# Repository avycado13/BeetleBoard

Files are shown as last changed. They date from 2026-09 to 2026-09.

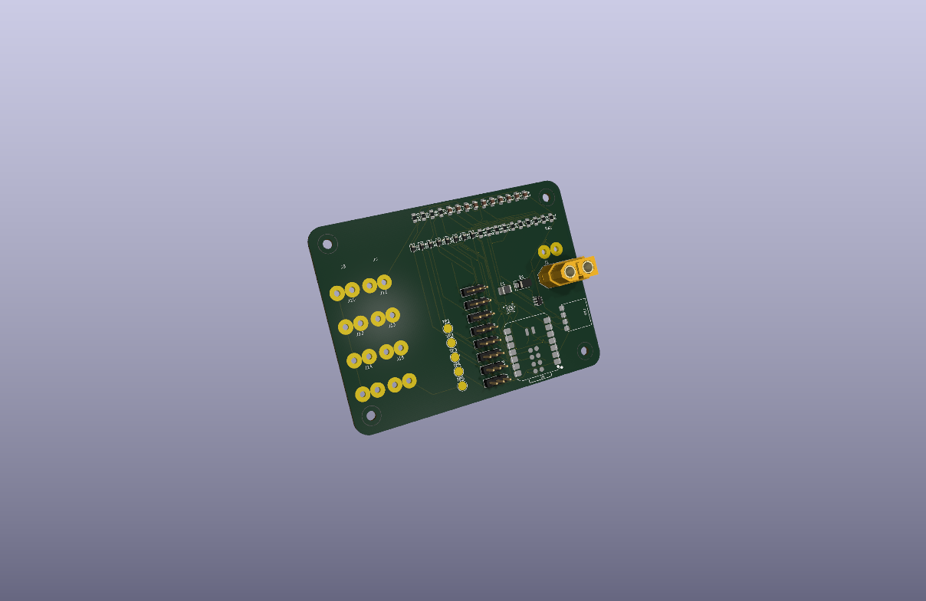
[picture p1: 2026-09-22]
images/BeetleBoard.png

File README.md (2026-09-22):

# BeetleBoard

Ever wanted to build a beetleweight but didn't want the huge mess of wires? No? Too bad. Meet BeetleBoard.
A perfect board for controlling your beetleweight battlebot using an ESP32.

PCB
3D View

## Features:
- 8 ports for ESCs
- 8 motor power ports
- Optional ExpressLRS Receiver
- 6 axis IMU with handling for up to 320Gs
- Software controllable battery undervoltage lockout circuitry
- Battery voltage sensing
- Powered by a XIAO ESP32-C6
- Ability to add a power switch (preferably fingertech)

## Why?
I built this because I saw battlebots at open sauce and thought "I want to make one of those". While looking through things about beetleweights and especially the ones with custom PCBs, I found out that most of the PCBs I found were specifically meant for one design and couldn't really be used for any type of bot. Coincidentally, My friend was trying to run a battlebots elective at our school and would need a control system to test before teaching the students.

## Bill of Materials (BOM)

This is just a rough list compiled from my schematic. The actual one is [here](./BOM.csv)

| Qty | Reference | Value | Package | Description |
|----:|---|---|---|---|
| 1 | U1 | XIAO ESP32-C6 SMD | XIAO | Seeed Studio XIAO ESP32-C6 module (main MCU) |
| 1 | U2 | TPS563200 | SOT-23-6 | 3A synchronous step-down buck converter (5V rail) |
| 1 | U3 | LSM6DSV320XTR | LGA-14 | 6-axis IMU, up to 320G |
| 1 | L1 | 4.7µH | 1210 | Buck converter power inductor |
| 5 | C1, C2, C3, C6, C8 | 22µF | 0805 | Bulk decoupling / output capacitance |
| 5 | C4, C5, C7, C9, C10 | 100nF | 0805 | Decoupling capacitors |
| 9 | R1-R6, R11-R13 | 33kΩ | 0805 | Resistor |
| 1 | R7 | 56kΩ | 0805 | Resistor |
| 1 | R8 | 10kΩ | 0805 | Resistor |
| 1 | R9 | 33.2kΩ | 0805 | Resistor |
| 1 | R10 | 120kΩ | 0805 | Resistor |
| 1 | R14 | 100kΩ | 0805 | Resistor |
| 1 | D1 | SMAJ40CA | SMA | 40V TVS diode (battery reverse/over-voltage protection) |
| 8 | D2-D9 | PESD5V0V1BA | SOD-323 | 5V ESD protection diodes |
| 1 | J1 | AMASS XT60-F | XT60 | Battery connector |
| 8 | J2-J7, J16, J17 | ESC signal port | 1×3 pin header 2.54mm | ESC signal power ports A-H |
| 8 | J8-J15 | VBAT ESC port | Solder wire 2-pin | Motor power ports |
| 1 | J18 | ELRS Receiver | BetaFPV Lite | Optional ExpressLRS receiver socket |
| 1 | SW1 | FingerTech Switch | Solder wire 2-pin | External power switch connection |
| 5 | TP1-TP5 | Test point | 3mm pad | Test/debug points (VBAT, 5V, GND, 3.3V, VBUS) |

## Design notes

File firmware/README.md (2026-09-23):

# BeetleBoard Example Firmware

Comprehensive firmware and modular driver examples for **BeetleBoard**, an ESP32-C6 powered beetleweight battlebot flight & motor control board designed by [avycado13](https://github.com/avycado13).

---

## 📋 Hardware Pinout & Architecture

Based directly on the `BeetleBoard.kicad_sch`, `power.kicad_sch`, and `imu.kicad_sch` schematics:

| Schematic Net | XIAO Pin | ESP32-C6 GPIO | Direction | Function & Hardware Circuitry |
|:---|:---:|:---:|:---:|:---|
| `VBAT_SNS` | **D0** | **GPIO 0** | Input (ADC1_CH0) | Battery voltage sense divider: $R_{10} = 120\text{ k}\Omega$, $R_9 = 33.2\text{ k}\Omega$, $C_7 = 100\text{ nF}$ filter |
| `BUCK_EN` | **D1** | **GPIO 1** | Output | Enable pin (Pin 5) of TPS563200 3A 5V Buck Regulator (active-HIGH) |
| `ESC_A` | **D2** | **GPIO 2** | Output (PWM) | ESC Header **J2** (Pin 1 Signal), 33k pulldown $R_3$, ESD diode $D_2$ |
| `ESC_B` | **D3** | **GPIO 21** | Output (PWM) | ESC Header **J3** (Pin 1 Signal), 33k pulldown $R_2$, ESD diode $D_3$ |
| `ESC_C` | **D4** | **GPIO 22** | Output (PWM) | ESC Header **J4** (Pin 1 Signal), 33k pulldown $R_1$, ESD diode $D_4$ |
| `ESC_D` | **MTDI** | **GPIO 5** | Output (PWM) | ESC Header **J5** (Pin 1 Signal), 33k pulldown $R_4$, ESD diode $D_5$ |
| `ESC_E` | **MTDO** | **GPIO 7** | Output (PWM) | ESC Header **J6** (Pin 1 Signal), 33k pulldown $R_5$, ESD diode $D_7$ |
| `ESC_F` | **MTCK** | **GPIO 6** | Output (PWM) | ESC Header **J7** (Pin 1 Signal), 33k pulldown $R_6$, ESD diode $D_6$ |
| `SPI_CS` | **D5** | **GPIO 23** | Output | Chip Select for LSM6DSV320XTR IMU (Pin 12 CS) |
| `XIAO_TX` | **D6** | **GPIO 16** | Output (UART TX) | J18 ELRS Receiver Header (Pin 1 RX on receiver) |
| `XIAO_RX` | **D7** | **GPIO 17** | Input (UART RX) | J18 ELRS Receiver Header (Pin 2 TX on receiver) |
| `SPI_SCK` | **D8** | **GPIO 19** | Output (SPI CLK) | LSM6DSV320XTR IMU (Pin 13 SCK), 100k pulldown $R_{14}$ |
| `SPI_MISO` | **D9** | **GPIO 20** | Input (SPI MISO) | LSM6DSV320XTR IMU (Pin 1 SDO), 33k pullup $R_{13}$ |
| `SPI_MOSI` | **D10** | **GPIO 18** | Output (SPI MOSI) | LSM6DSV320XTR IMU (Pin 14 SDI) |
| *LED* | Internal | **GPIO 15** | Output | XIAO ESP32-C6 onboard user LED (Active-LOW: LOW=ON, HIGH=OFF) |
| `+5V` | **5V** | VBUS Rail | Power | Generated by TPS563200 buck regulator from battery, powers ESCs & ELRS |
| `+3V3` | **3V3** | 3.3V Rail | Power | Generated by XIAO onboard LDO regulator, powers LSM6DSV320XTR IMU |

> [!NOTE]
> On the PCB, ESC headers **J16** (`ESC_G`) and **J17** (`ESC_H`) include ESD diodes and pulldown resistors for expansion or passthrough, but their signal pins are unrouted to the MCU on this revision.

---

## ⚡ Subsystem Details

### 1. Battery Voltage Sensing & Software UVLO
- **Circuit**: Voltage divider with $R_{10} = 120\text{ k}\Omega$ (top) and $R_9 = 33.2\text{ k}\Omega$ (bottom).
  $$\text{Ratio} = \frac{33.2}{120 + 33.2} = \frac{33.2}{153.2} \approx 0.21671$$
  $$V_{\text{BAT}} = V_{\text{pin}} \times \frac{153.2}{33.2} \approx V_{\text{pin}} \times 4.61446$$
- **Software Undervoltage Lockout (UVLO)**:
  - Automatically identifies battery cell count (2S: ~7.4V, 3S: ~11.1V, 4S: ~14.8V).
  - Continuous exponential moving average filter rejects transient motor punch-out voltage sag.
  - If average cell voltage stays below **3.30V** for $>1.5\text{ s}$, the MCU pulls `BUCK_EN` (GPIO 1) **LOW**, disabling the TPS563200 5V buck regulator to save the LiPo pack from over-discharge damage.

### 2. 6-Channel ESC PWM Generator
- Channels ESC A through F are driven by the ESP32-C6 LEDC hardware PWM generator at **50 Hz** (20 ms period) with **14-bit** resolution.
- Supports both standard unidirectional throttle ($1000\mu\text{s}$ to $2000\mu\text{s}$) and bidirectional drive ($1000\mu\text{s}$ reverse, $1500\mu\text{s}$ neutral, $2000\mu\text{s}$ forward).
- Includes **software arming safety** and **instant emergency stop**.

### 3. LSM6DSV320XTR 6-Axis High-G IMU
- High-g 6-axis IMU rated up to **$\pm 320\text{ g}$** and **$\pm 4000\text{ dps}$**, specifically designed to withstand violent battlebot impacts and meltybrain spin rates.
- Connected via a dedicated 4-wire SPI bus at 4 MHz (Mode 0).
- Verifies identity via `WHO_AM_I` (`0x73`), configures 120 Hz ODR, and streams calibrated acceleration ($g$), angular rates ($\text{dps}$), and rotational spin rate ($\text{RPM}$).

### 4. ExpressLRS (ELRS) / CRSF Receiver
- Standard 4-pin header for BetaFPV Lite, Radiomaster, or Happymodel ELRS receivers.
- Communicates over UART (Serial1) at **420,000 baud** using the standard CRSF protocol.
- Includes full 16-channel 11-bit packet unpacking, Link Quality (LQ), RSSI telemetry, and failsafe detection ($>250\text{ ms}$ packet timeout).

---

## 📂 Project Structure

```
firmware/
├── platformio.ini              # PlatformIO project configuration
├── README.md                   # This documentation
├── include/
│   └── beetleboard_pins.h      # Master pinout & schematic hardware definitions
├── src/
│   ├── main.cpp                # Main production firmware with CLI & control loop
│   ├── power_manager.h/.cpp    # Battery sensing, cell detection & UVLO buck control
│   ├── esc_driver.h/.cpp       # 6-channel LEDC PWM ESC driver
│   ├── imu_lsm6dsv.h/.cpp      # Hardware SPI driver for LSM6DSV320X IMU
│   └── elrs_receiver.h/.cpp    # ExpressLRS CRSF serial protocol decoder
└── examples/
    ├── 01_blink_and_power/     # Standalone: 5V Buck Rail enable & user LED blink
    ├── 02_battery_monitor/     # Standalone: ADC voltage divider & UVLO test
    ├── 03_esc_motor_test/      # Standalone: 6-channel ESC PWM bench sweep
    ├── 04_imu_read_spi/        # Standalone: LSM6DSV320X SPI read & streaming
    └── 05_elrs_telemetry/      # Standalone: ELRS CRSF RC channel decoder
```

---

## 🚀 Building & Flashing

### Option A: Using PlatformIO (Recommended)

1. Open VS Code with the **PlatformIO IDE** extension installed.
2. Open the `firmware/` folder (`File -> Open Folder...`).
3. Connect your BeetleBoard via USB-C.
4. Click **Build** (`✓`) or **Upload** (`→`) on the PlatformIO status bar.
5. Open the Serial Monitor at **115,200 baud**.

Or via CLI:
```bash
cd firmware
pio run --target upload
pio device monitor -b 115200
```

### Option B: Using Arduino IDE

1. Install the **esp32** board package by Espressif (`Tools -> Board -> Boards Manager -> esp32` version 3.0.0 or newer).
2. Select Board: **"Seeed Studio XIAO ESP32C6"** (or **"ESP32C6 Dev Module"**).
3. Set the following under the `Tools` menu:
   - **USB CDC On Boot**: `"Enabled"`
   - **Upload Mode**: `"UART0 / Hardware CDC"`
   - **Flash Size**: `"4MB"`
4. Open `firmware/src/main.cpp` (or any `.ino` sketch under `firmware/examples/`).
5. Click **Upload** and open the Serial Monitor at 115200 baud.

---

## 💻 Interactive Serial Console

The primary firmware (`main.cpp`) includes a built-in USB Serial command interface:

| Key | Action |
|:---:|:---|
| `s` | **Print full system status** (Battery V, LiPo cells, 5V buck state, ESC PWM, IMU, ELRS) |
| `b` | **Toggle 5V Buck Regulator** (Force enable/disable TPS563200 via `BUCK_EN` GPIO 1) |
| `a` | **Toggle Software Arming** (Arm/Disarm motor outputs) |
| `m` | **Motor Bench Sweep Test** (Gentle 3-second throttle ramp on ESC A) |
| `t` | **Stream IMU Telemetry** (Real-time Accel X/Y/Z, Gyro X/Y/Z, and Yaw RPM) |
| `r` | **Stream ELRS RC Channels** (Real-time stick positions, Link Quality, RSSI) |
| `v` | **Stream Battery Voltage** (Continuous voltage & UVLO status) |
| `u` | **Reset UVLO Cutoff** (Clear undervoltage trip and re-enable 5V rail) |
| `h` / `?` | **Show Help Menu** |

---

## 🛡️ Safety Guidelines for Battlebot Testing

> [!CAUTION]
> **ALWAYS REMOVE ALL WEAPONS AND PROPELLERS BEFORE BENCH TESTING.**
> 1. Ensure the board is disarmed before powering on the battery.
> 2. Keep the robot propped up on a stand so drive wheels cannot contact the bench surface.
> 3. Verify failsafe operation by turning off your transmitter while motors are idling; all ESC outputs should immediately revert to $1000\mu\text{s}$ (stopped).

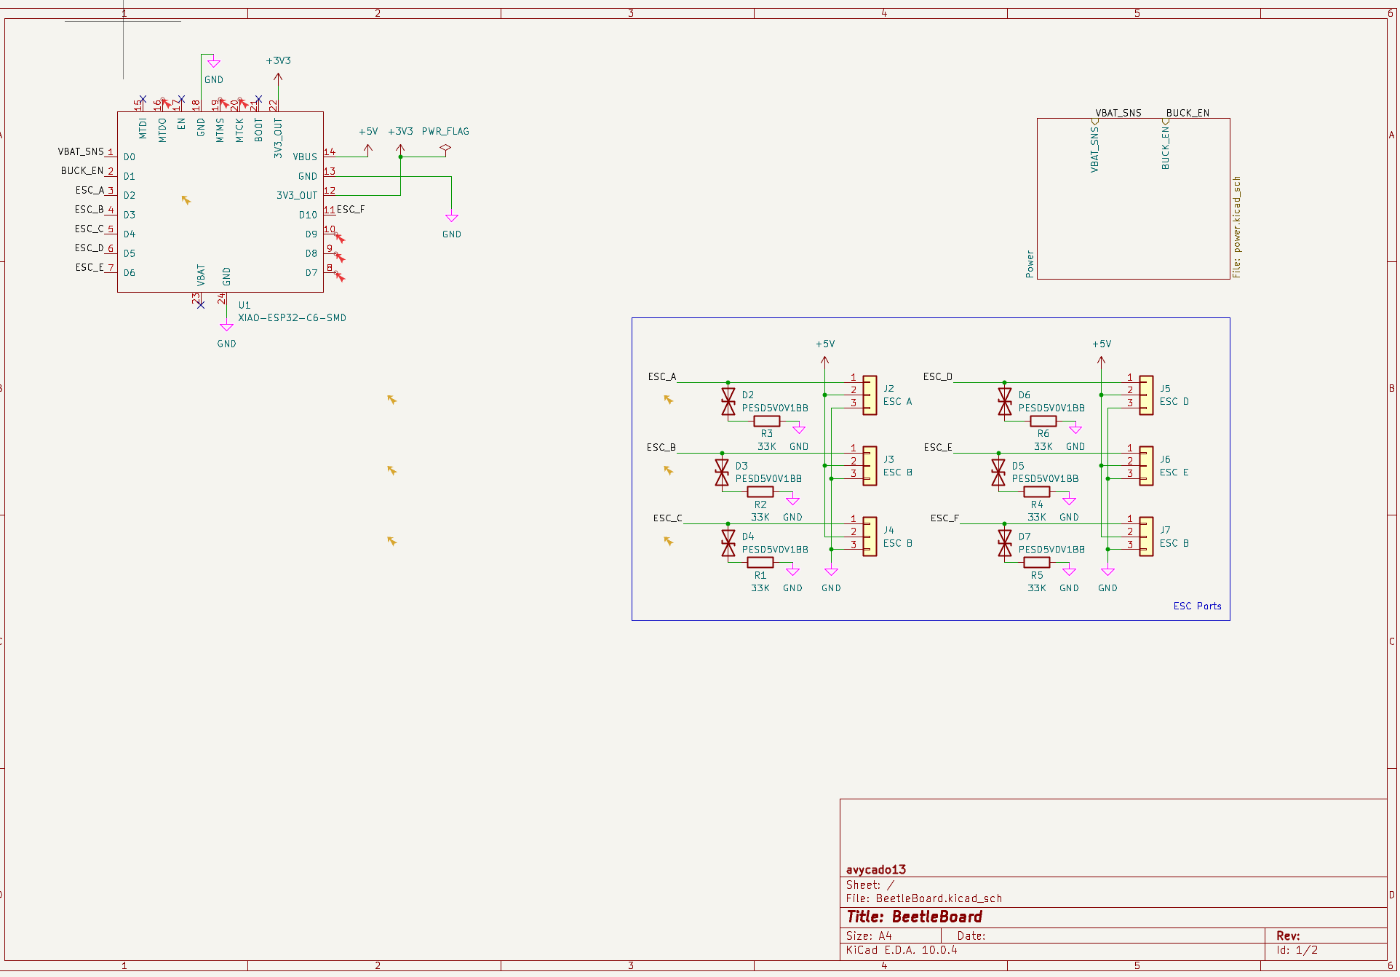
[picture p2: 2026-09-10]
images/beetleboard-3.png

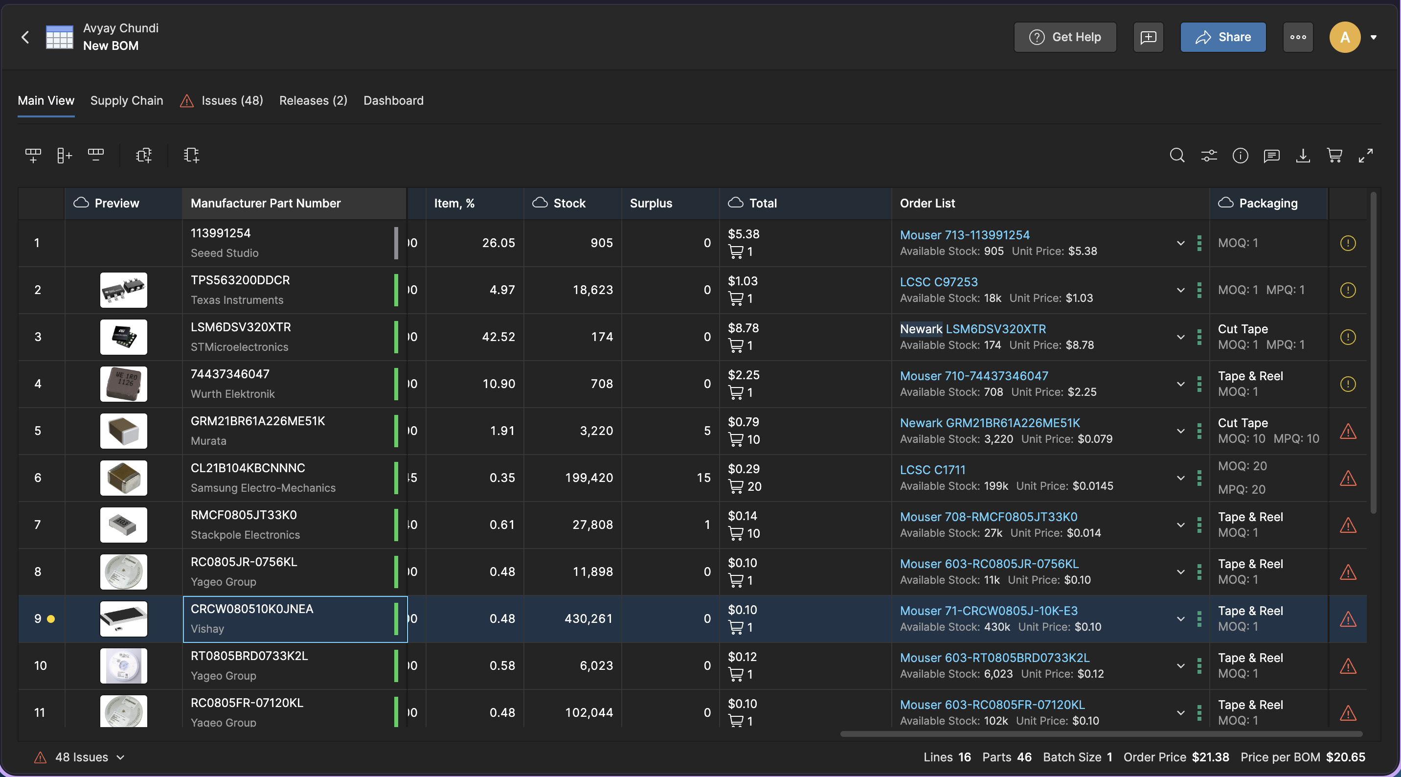
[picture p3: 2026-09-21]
images/beetleboard-13.png

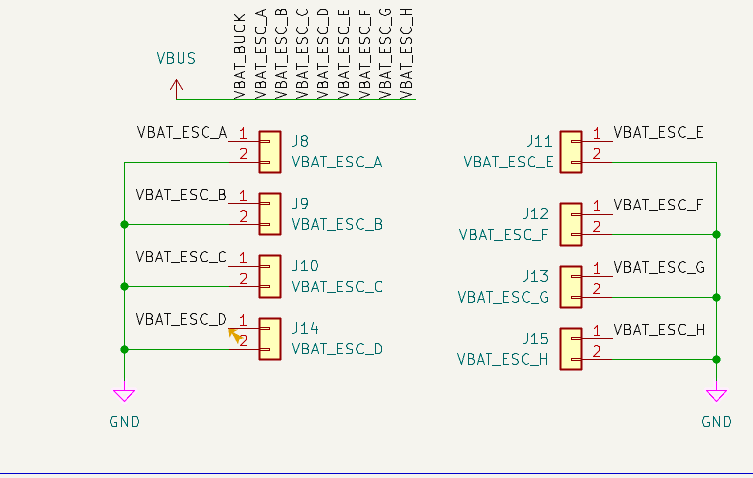
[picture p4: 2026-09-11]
images/beetleboard-5.png

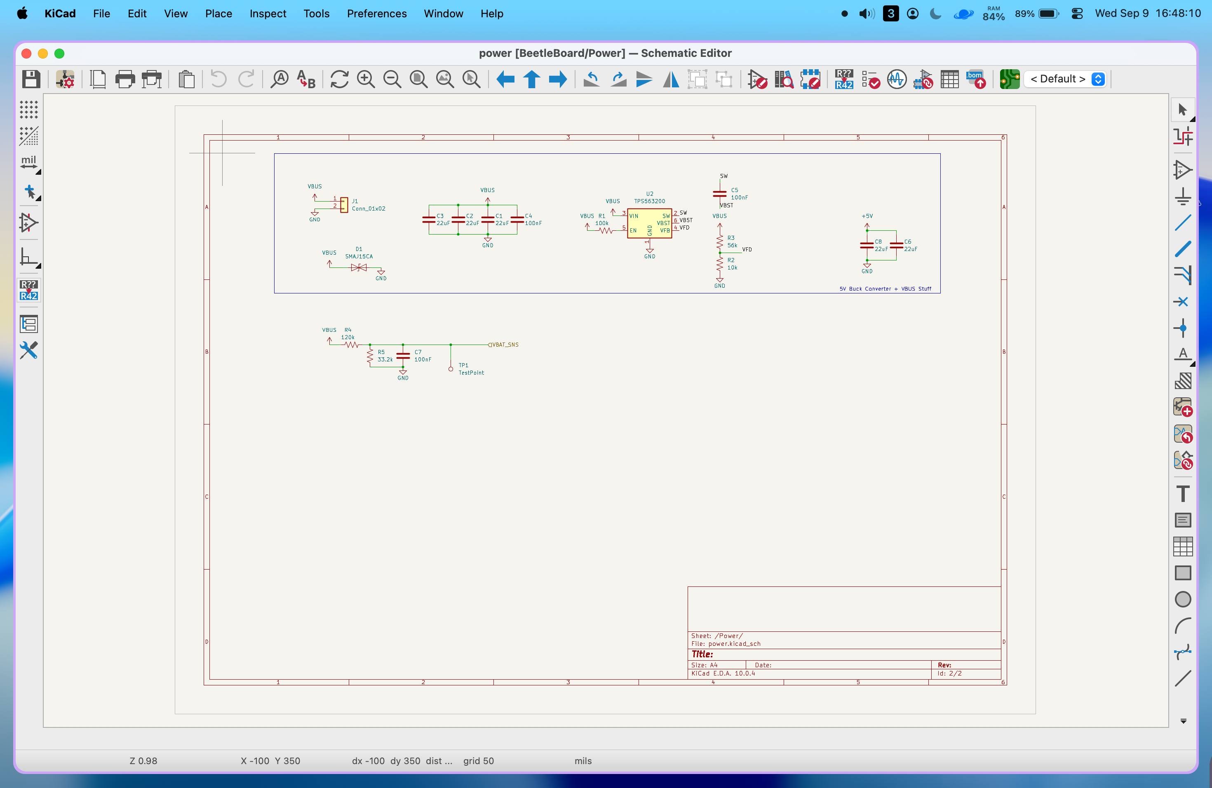
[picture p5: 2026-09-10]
images/beetleboard-1.png

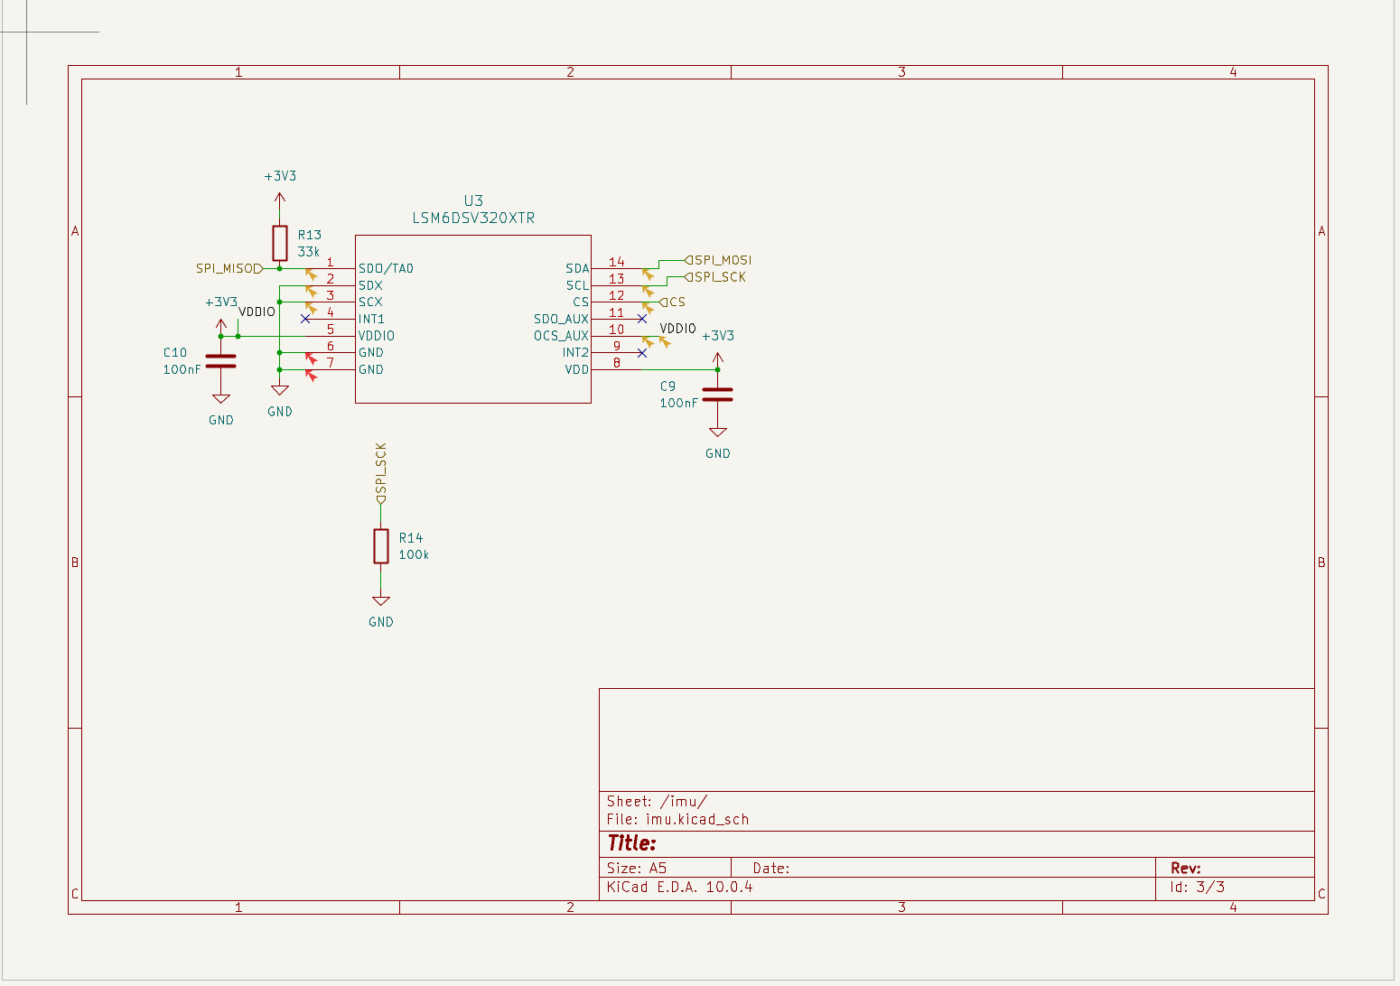
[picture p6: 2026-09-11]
images/beetleboard-6.png

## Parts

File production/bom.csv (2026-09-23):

Designator | Footprint | Quantity | Value | LCSC Part #
C1, C2, C3, C6, C8 | 0805 | 5 | 22uF
C10, C4, C5, C7, C9 | 0805 | 5 | 100nF
D1 | D_SMA | 1 | SMAJ40CA
D2, D3, D4, D5, D6, D7, D8, D9 | D_SOD-323 | 8 | PESD5V0V1BB
J1 | AMASS_XT60-F_1x02_P7.20mm_Vertical | 1 | Battery Connector
J10 | Power_SolderPad_2Pin_P5.08mm_D2.0mm | 1 | VBAT_ESC_C
J11 | Power_SolderPad_2Pin_P5.08mm_D2.0mm | 1 | VBAT_ESC_E
J12 | Power_SolderPad_2Pin_P5.08mm_D2.0mm | 1 | VBAT_ESC_F
J13 | Power_SolderPad_2Pin_P5.08mm_D2.0mm | 1 | VBAT_ESC_G
J14 | Power_SolderPad_2Pin_P5.08mm_D2.0mm | 1 | VBAT_ESC_D
J15 | Power_SolderPad_2Pin_P5.08mm_D2.0mm | 1 | VBAT_ESC_H
J16 | PinHeader_1x03_P2.54mm_Vertical | 1 | ESC G
J17 | PinHeader_1x03_P2.54mm_Vertical | 1 | ESC H
J18 | BetaFPV_ELRS_Lite | 1 | ELRS Reciever
J2 | PinHeader_1x03_P2.54mm_Vertical | 1 | ESC A
J3 | PinHeader_1x03_P2.54mm_Vertical | 1 | ESC B
J4 | PinHeader_1x03_P2.54mm_Vertical | 1 | ESC C
J5 | PinHeader_1x03_P2.54mm_Vertical | 1 | ESC D
J6 | PinHeader_1x03_P2.54mm_Vertical | 1 | ESC E
J7 | PinHeader_1x03_P2.54mm_Vertical | 1 | ESC F
J8 | Power_SolderPad_2Pin_P5.08mm_D2.0mm | 1 | VBAT_ESC_A
J9 | Power_SolderPad_2Pin_P5.08mm_D2.0mm | 1 | VBAT_ESC_B
L1 | 1210 | 1 | 4.7uH
R1, R11, R12, R13, R2, R3, R4, R5, R6 | 0805 | 9 | 33K
R10 | 0805 | 1 | 120k
R14 | 0805 | 1 | 100k
R7 | 0805 | 1 | 56K
R8 | 0805 | 1 | 10K
R9 | 0805 | 1 | 33.2k
SW1 | Power_SolderPad_2Pin_P5.08mm_D2.0mm | 1 | FingerTech Switch
TP1 | TestPoint_Pad_D3.0mm | 1 | TP_VBAT_SNS
TP2 | TestPoint_Pad_D3.0mm | 1 | TP_5V
TP3 | TestPoint_Pad_D3.0mm | 1 | TP_GND
TP4 | TestPoint_Pad_D3.0mm | 1 | TP_3V3
TP5 | TestPoint_Pad_D3.0mm | 1 | TP_VBAT(VBUS)
U1 | XIAO-ESP32-C6-SMD | 1 | XIAO-ESP32-C6-SMD
U2 | SOT-23-6 | 1 | TPS563200
U3 | LGA-14L_2p5X3X0p83_STM | 1 | LSM6DSV320XTR

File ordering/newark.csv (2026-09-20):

Manufacturer Part Number | Manufacturer | Quantity | Order List | Supplier Name | Supplier Part Number | Order List (Supplier Link) | Packaging | MOQ | MPQ | Unit Price, $ | Stock | Supplier Order Quantity | Subtotal, $
LSM6DSV320XTR | STMicroelectronics | 1 | Newark LSM6DSV320XTR | Newark | LSM6DSV320XTR | https://octopart.com/opatz8j6/a1 | Cut Tape | 1 | 1 | 8.78 | 174 | 1 | 8.78
GRM21BR61A226ME51K | Murata | 5 | Newark GRM21BR61A226ME51K | Newark | GRM21BR61A226ME51K | https://octopart.com/opatz8j6/a1 | Cut Tape | 10 | 10 | 0.079 | 3220 | 10 | 0.790
RC0805FR-07100KL | Yageo Group | 1 | Newark RC0805FR-07100KL | Newark | RC0805FR-07100KL | https://octopart.com/opatz8j6/a1 | Cut Tape | 1 | 1 | 0.101 | 113917 | 1 | 0.101

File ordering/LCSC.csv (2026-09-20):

Manufacturer Part Number | Manufacturer | Quantity | Order List | Supplier Name | Supplier Part Number | Order List (Supplier Link) | Packaging | MOQ | MPQ | Unit Price, $ | Stock | Supplier Order Quantity | Subtotal, $
TPS563200DDCR | Texas Instruments | 1 | LCSC C97253 | LCSC | C97253 | https://octopart.com/opatz8j6/a1 |  | 1 | 1 | 1.03 | 18623 | 1 | 1.03
CL21B104KBCNNNC | Samsung Electro-Mechanics | 5 | LCSC C1711 | LCSC | C1711 | https://octopart.com/opatz8j6/a1 |  | 20 | 20 | 0.0145 | 199420 | 20 | 0.2900
PESD5V0V1BA,115 | Nexperia | 8 | LCSC C552583 | LCSC | C552583 | https://octopart.com/opatz8j6/a1 |  | 10 | 10 | 0.0508 | 47280 | 10 | 0.5080
XT60-F | Amass | 1 | LCSC C98734 | LCSC | C98734 | https://octopart.com/opatz8j6/a1 |  | 1 | 1 | 0.4172 | 33851 | 1 | 0.4172

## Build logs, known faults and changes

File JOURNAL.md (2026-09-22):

---
title: "BeetleBoard"
github: "avycado13/beetleboard"
description: "a basic board for making versatile beetleweight battlebots"
created_at: "2026-09-08"
---

My friend wants to do more battlebot type things with 5th and 6th graders so I thought I might make a board that has enough motor and servo ports to be useful for all types of bots and not constrained to one. I guess I am calling it BeetleBoard!
 
# September 8: Added Basic Power Circuitry
I made my circuit to take a LiPo battery and then first it goes through a TVS Diode to protect it from voltage spikes. Then it gets decoupled through 4 Capacitors and toned down to 5v with a buck converter. I also added some battery charge sensing. (I took heavy inspiration from Kieran's [Holy Guacamole](https://github.com/taciturnaxolotl/holy-guacamole/))

Power subsheet
**Total time spent: 2h**

# September 9: Fixed Power Circuitry

So I might be a bit dumb and have for gotten some stuff, so I fixed that up and needed to fiddle with KiCad libraries.
Also, I kinda gave up on implementing a proper undervolting lock out circuit in hardware, so I will just use my voltage sensing to control the enable pin in software. (I forgot to commit this 4 hours ago)

Power Subsheet Rev. 2
**Total time spent: 1h**

# September 9: ESC Ports
After taking way too long to understand the difference between PWM and DShot, I understand it now. Interestingly you can use the same connector layout for both (I think). I added 6 ports for ESCs, they all look like servo ports and can function as such because they can do both DShot and PWM. It might seem a bit excessive to have 6 Servo ports, but because this is for experimentation it should turn out fine. Also did I tell you I decided on a XIAO ESP32-C6 for it?

Main Sheet
**Total time spent: 2h**

# September 10: Added 6 Axis IMU
I was on a huddle with Kian and he told me about the MPU-6050 which is a 6 axis imu. I was debating whether to put an imu on this as it would have been a lot of work to wire up multiple so this board simplifies it a lot. it was actually really simple to wire up as it just used i2c (TIL that its pronounced I squared c) I also added a test point on the 5V Rail and GND.
I might add a header on the board to connect to a radio receiver as apparently ESP32 WiFi signals don't work that great.

New schematic with IMU
**Total time spent: 1h**

# September 10: Added Power distrubution
I kinda forgot that the ESCs require a seperate source of power with a higher voltage to actually power the motors, so i added some power distrubution to the board. It goes directly from the battery through a TVS Diode and some capactors to clean up voltage spikes and decouple it then gets split into 8 connectors for the ESCs and one for the buck converter. I also added an SPST switch on the power connector where i can eventually put a FingerTech Switch or just solder them together.

New power subsheet with distrubution
**Total time spent: 1h**

# September 11: Fixed IMU
I realized that my original IMU wouldn't be able to handle more than 16G, which is really low because on impact it could hit 200G and for meltybrains it would overload because of spinny. Instead, I replaced it with an LSM6DSV320XTR 6 axis IMU that could handle up to 300Gs. I wired it over SPI to connect everything and I put it in its own sheet.

New IMU over SPI
**Total time spent: 1.5h**

# September 11: Added Port for ExpressLRS Receiver
I added a connector for an ExpressLRS receiver because ESP32 bluetooth/WiFi is supposedly really unreliable. It should communicate over UART.

New ELRS Reciever
**Total time spent: 0.5h**

# September 13: Started PCB Layout
I assigned the footprints for components and made a really crappy layout for the PCB that kinda looks like a guitar.

PCB
**Total time spent: 0.5h**

# September 14: Redid PCB Layout and Routed
I redid the layout to be less weird shaped and cheaper to fab. I also routed it in just 2 layers!
Because its about 100mm by 70mm it should only cost 5 bucks to fab.

New PCB Layout
**Total time spent: 1.5h**

# September 17: Wrote README
Today, I prepped it for shipping and mainly wrote the readme. I don't think I need a photo of the README because you can read that. I added a comprehensive list of features!

edit: turns out i do :(

README
**Total time spent: 1h**

# September 20: Made better BOM

I already have a BOM in my README, but I went to Octopart and made a better BOM and consolidated my parts so i will only have to order from three suppliers: LCSC, Mouser, and Newark.

Altium BOM Portal

**Total time spent: 1h**

# September 21: Redid Layout
I redid the layout of the PCB to be neater and changed the solder wire things to be a new custom footprint of 2 5mm circle pads spaced about 5mm apart. I also added M3 Mounting holes offset 6mm x 6mm from each edge. In addition, I also filleted the corners for looks. I forgot to put it when I took the picture but I also added some basic silkscreen.
PCB with new layout
**Total time spent: 2h**

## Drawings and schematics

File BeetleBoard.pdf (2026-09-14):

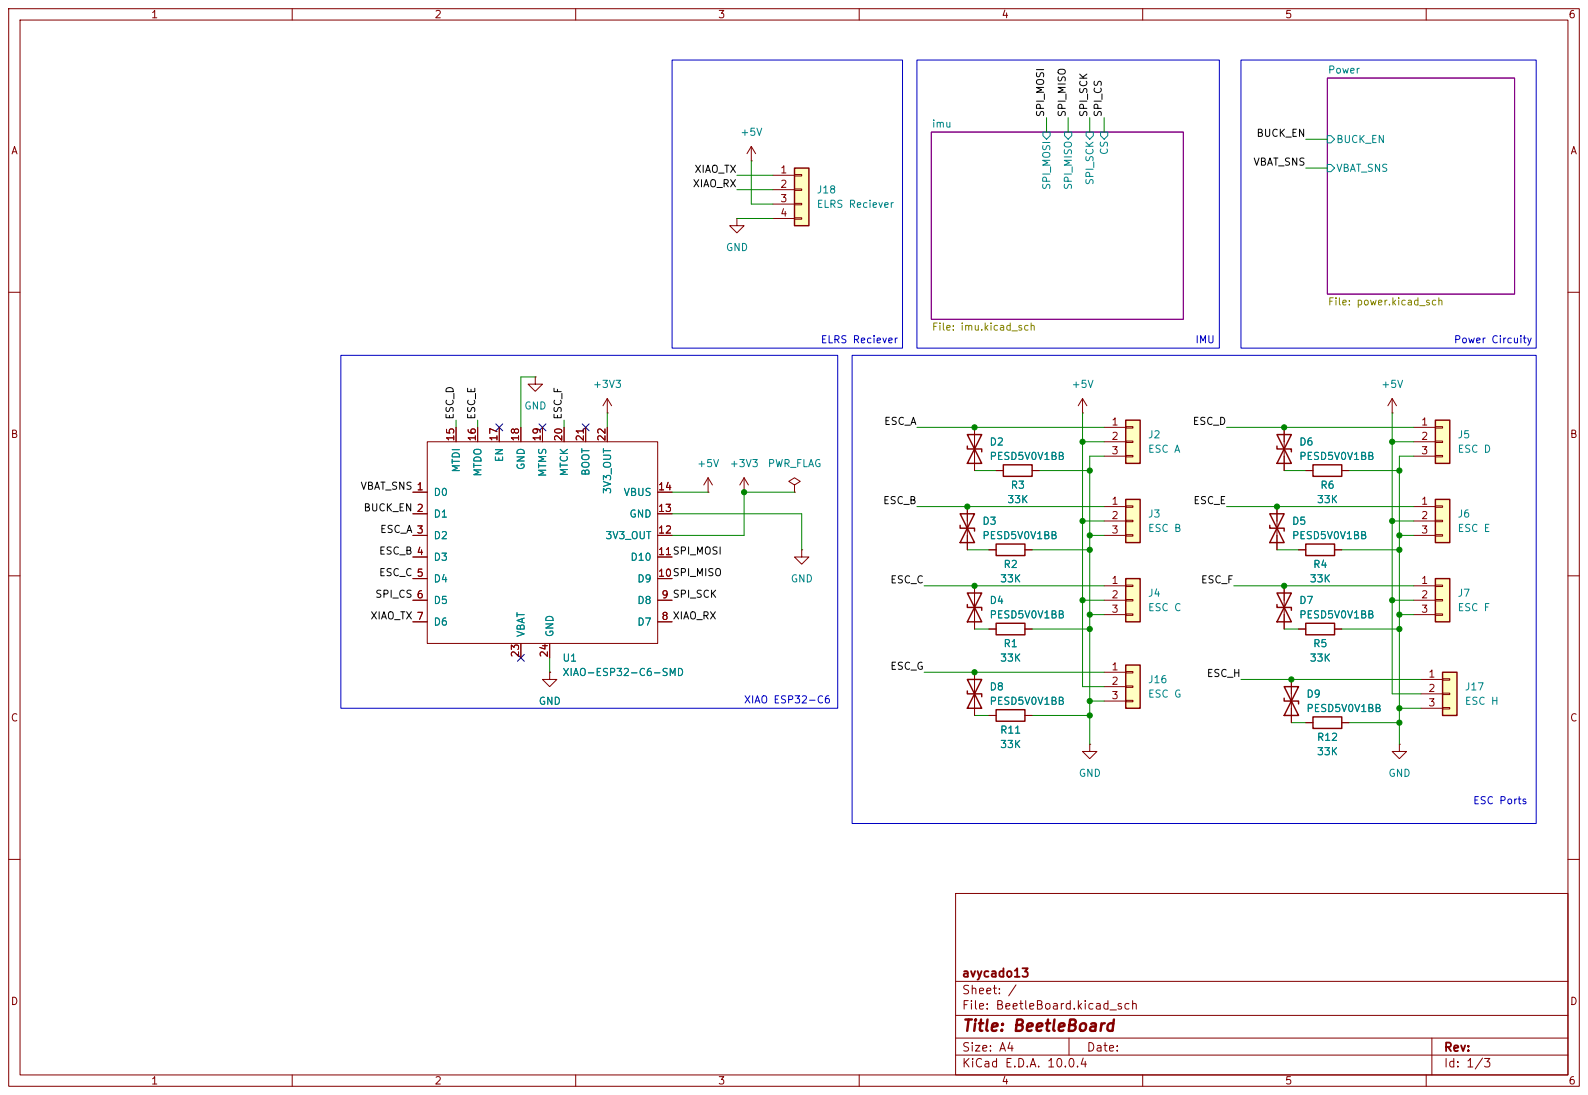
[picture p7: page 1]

Size: A4 | Rev:
KiCad E.D.A. 10.0.4 | Id: 1/3

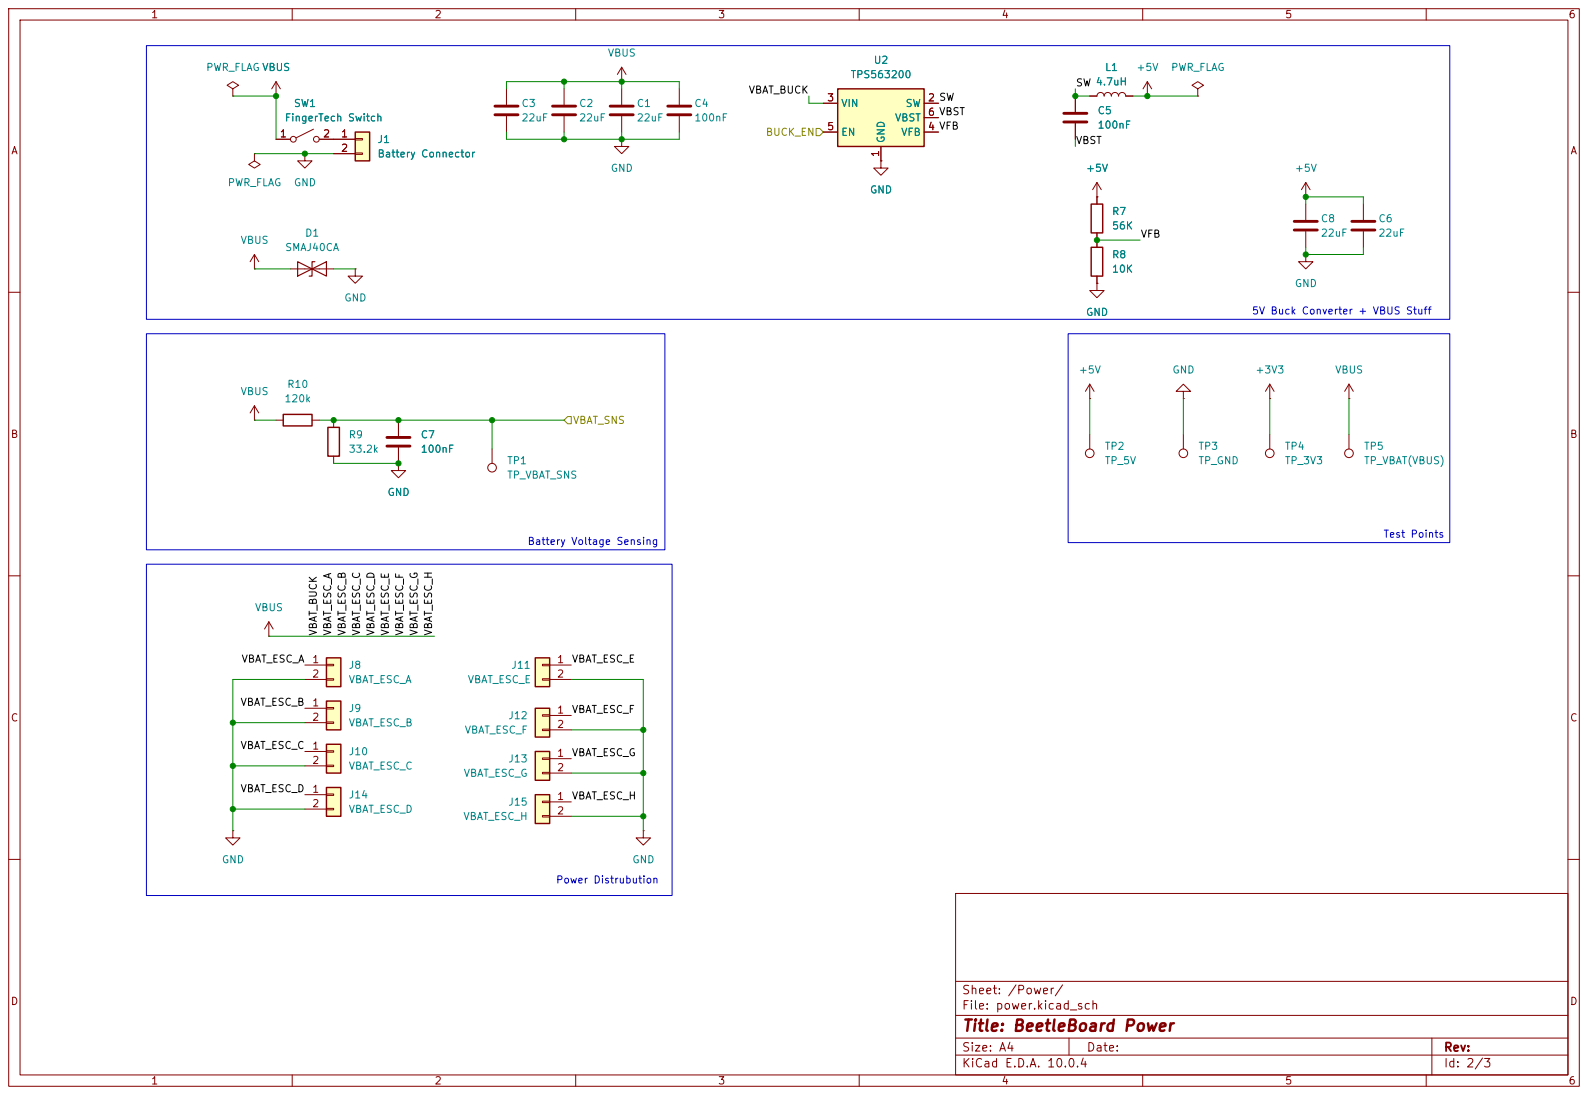
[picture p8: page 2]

Size: A4 | Rev:
KiCad E.D.A. 10.0.4 | Id: 2/3

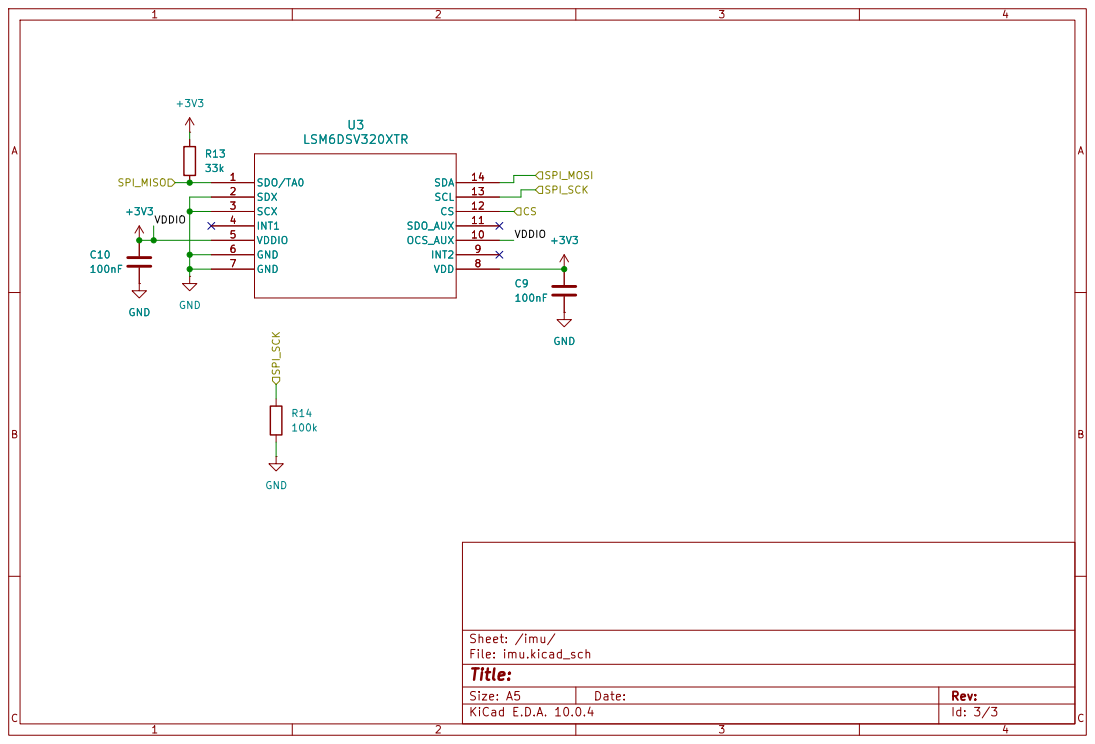
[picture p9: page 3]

Size: A5 | Rev: | C Date:
KiCad E.D.A. 10.0.4 | Id: 3/3

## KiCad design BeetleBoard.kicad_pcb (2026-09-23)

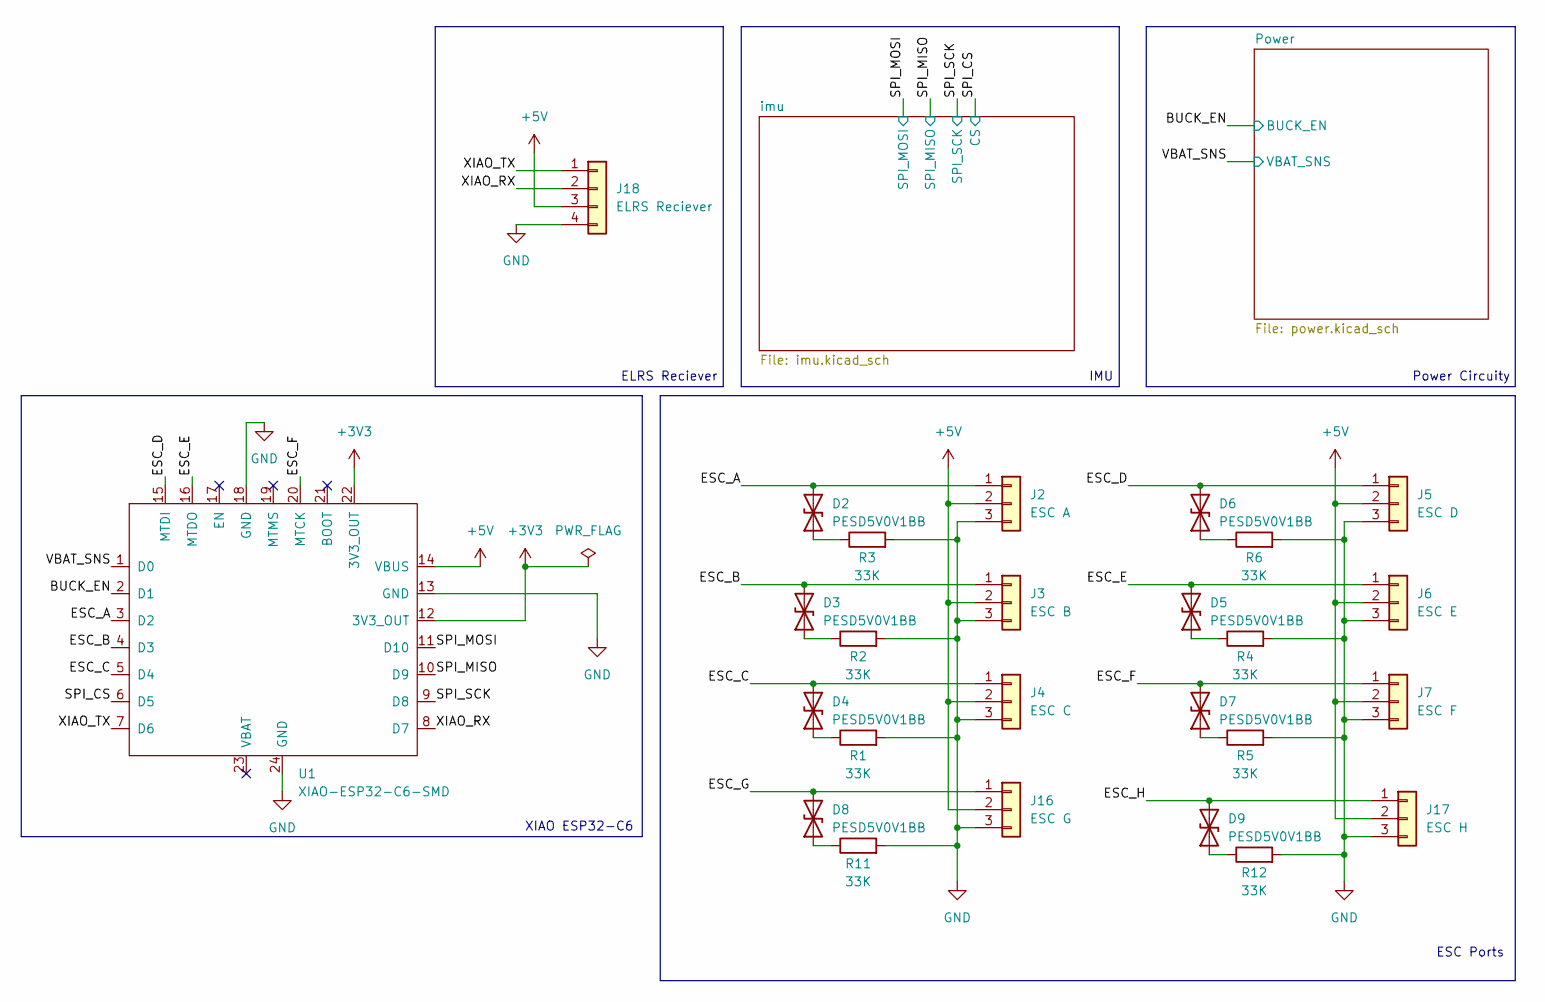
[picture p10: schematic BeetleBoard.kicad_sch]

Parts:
D2, D3, D4, D5, D6, D7, D8, D9: PESD5V0V1BB; D_SOD-323
J2: ESC A; PinHeader_1x03_P2.54mm_Vertical
J3: ESC B; PinHeader_1x03_P2.54mm_Vertical
J4: ESC C; PinHeader_1x03_P2.54mm_Vertical
J5: ESC D; PinHeader_1x03_P2.54mm_Vertical
J6: ESC E; PinHeader_1x03_P2.54mm_Vertical
J7: ESC F; PinHeader_1x03_P2.54mm_Vertical
J16: ESC G; PinHeader_1x03_P2.54mm_Vertical
J17: ESC H; PinHeader_1x03_P2.54mm_Vertical
J18: ELRS Reciever; BetaFPV_ELRS_Lite
R1, R2, R3, R4, R5, R6, R11, R12: 33K; R_0805_2012Metric_Pad1.20x1.40mm_HandSolder
U1: XIAO-ESP32-C6-SMD

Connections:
+3V3: U1.12 (3V3_OUT), U1.22 (3V3_OUT); also elsewhere on the board
+5V: J2.2 (+5V), J3.2 (+5V), J4.2 (+5V), J5.2 (+5V), J6.2 (+5V), J7.2 (+5V), J16.2 (+5V), J17.2 (+5V), J18.3, U1.14 (VBUS); also elsewhere on the board
/BUCK_EN: U1.2 (D1); also elsewhere on the board
/ESC_A: D2.2 (A2), J2.1 (DShot/PWM), U1.3 (D2)
/ESC_B: D3.2 (A2), J3.1 (DShot/PWM), U1.4 (D3)
/ESC_C: D4.2 (A2), J4.1 (DShot/PWM), U1.5 (D4)
/ESC_D: D6.2 (A2), J5.1 (DShot/PWM), U1.15 (MTDI)
/ESC_E: D5.2 (A2), J6.1 (DShot/PWM), U1.16 (MTDO)
/ESC_F: D7.2 (A2), J7.1 (DShot/PWM), U1.20 (MTCK)
/ESC_G: D8.2 (A2), J16.1 (DShot/PWM)
/ESC_H: D9.2 (A2), J17.1 (DShot/PWM)
/SPI_CS: U1.6 (D5); also elsewhere on the board
/SPI_MISO: U1.10 (D9); also elsewhere on the board
/SPI_MOSI: U1.11 (D10); also elsewhere on the board
/SPI_SCK: U1.9 (D8); also elsewhere on the board
/VBAT_SNS: U1.1 (D0); also elsewhere on the board
/XIAO_RX: J18.2, U1.8 (D7)
/XIAO_TX: J18.1, U1.7 (D6)
GND: J2.3 (GND), J3.3 (GND), J4.3 (GND), J5.3 (GND), J6.3 (GND), J7.3 (GND), J16.3 (GND), J17.3 (GND), J18.4, R1.2, R2.2, R3.2, R4.2, R5.2, R6.2, R11.2, R12.2, U1.13 (GND), U1.18 (GND), U1.24 (GND); also elsewhere on the board
unnamed: D2.1 (A1), R3.1
unnamed: D3.1 (A1), R2.1
unnamed: D4.1 (A1), R1.1
unnamed: D5.1 (A1), R4.1
unnamed: D6.1 (A1), R6.1
unnamed: D7.1 (A1), R5.1
unnamed: D8.1 (A1), R11.1
unnamed: D9.1 (A1), R12.1

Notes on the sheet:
Power Circuity
XIAO ESP32-C6
ELRS Reciever
IMU
ESC Ports

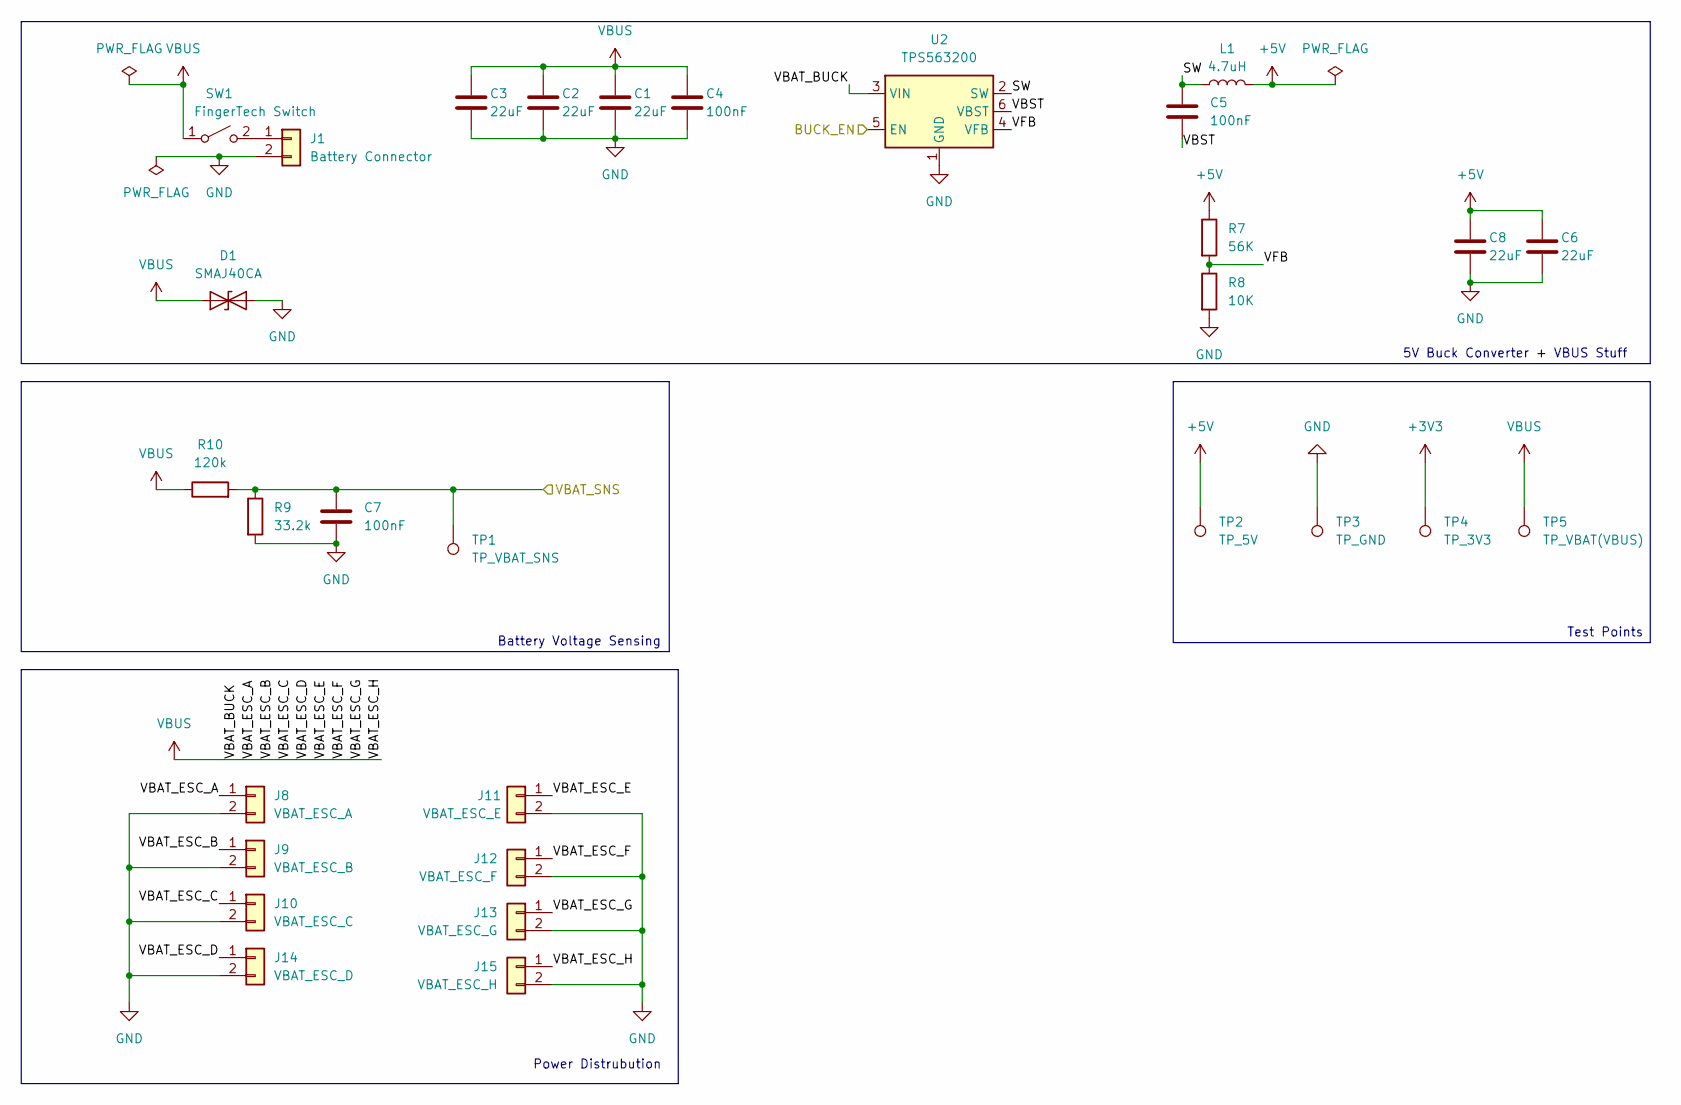
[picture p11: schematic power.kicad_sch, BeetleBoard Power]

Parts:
C1, C2, C3, C6, C8: 22uF; C_0805_2012Metric_Pad1.18x1.45mm_HandSolder
C4, C5, C7: 100nF; C_0805_2012Metric_Pad1.18x1.45mm_HandSolder
D1: SMAJ40CA; D_SMA
J1: Battery Connector; AMASS_XT60-F_1x02_P7.20mm_Vertical
J8: VBAT_ESC_A; Power_SolderPad_2Pin_P5.08mm_D2.0mm
J9: VBAT_ESC_B; Power_SolderPad_2Pin_P5.08mm_D2.0mm
J10: VBAT_ESC_C; Power_SolderPad_2Pin_P5.08mm_D2.0mm
J11: VBAT_ESC_E; Power_SolderPad_2Pin_P5.08mm_D2.0mm
J12: VBAT_ESC_F; Power_SolderPad_2Pin_P5.08mm_D2.0mm
J13: VBAT_ESC_G; Power_SolderPad_2Pin_P5.08mm_D2.0mm
J14: VBAT_ESC_D; Power_SolderPad_2Pin_P5.08mm_D2.0mm
J15: VBAT_ESC_H; Power_SolderPad_2Pin_P5.08mm_D2.0mm
L1: 4.7uH; L_1210_3225Metric_Pad1.42x2.65mm_HandSolder
R7: 56K; R_0805_2012Metric_Pad1.20x1.40mm_HandSolder
R8: 10K; R_0805_2012Metric_Pad1.20x1.40mm_HandSolder
R9: 33.2k; R_0805_2012Metric_Pad1.20x1.40mm_HandSolder
R10: 120k; R_0805_2012Metric_Pad1.20x1.40mm_HandSolder
SW1: FingerTech Switch; Power_SolderPad_2Pin_P5.08mm_D2.0mm
TP1: TP_VBAT_SNS; TestPoint_Pad_D3.0mm
TP2: TP_5V; TestPoint_Pad_D3.0mm
TP3: TP_GND; TestPoint_Pad_D3.0mm
TP4: TP_3V3; TestPoint_Pad_D3.0mm
TP5: TP_VBAT(VBUS); TestPoint_Pad_D3.0mm
U2: TPS563200; SOT-23-6

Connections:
+3V3: TP4.1 (1_1); also elsewhere on the board
+5V: C6.1, C8.1, L1.2, R7.1, TP2.1 (1_1); also elsewhere on the board
/BUCK_EN: U2.5 (EN); also elsewhere on the board
/Power/SW: C5.1, L1.1, U2.2 (SW)
/Power/VBST: C5.2, U2.6 (VBST)
/Power/VFB: R7.2, R8.1, U2.4 (VFB)
/VBAT_SNS: C7.1, R9.1, R10.2, TP1.1 (1_1); also elsewhere on the board
GND: C1.2, C2.2, C3.2, C4.2, C6.2, C7.2, C8.2, D1.2 (A2), J1.2, J8.2, J9.2, J10.2, J11.2, J12.2, J13.2, J14.2, J15.2, R8.2, R9.2, TP3.1 (1_1), U2.1 (GND); also elsewhere on the board
unnamed: J1.1, SW1.2 (B)
VBUS: C1.1, C2.1, C3.1, C4.1, D1.1 (A1), J8.1 (Pin_1_1), J9.1 (Pin_1_1), J10.1 (Pin_1_1), J11.1 (Pin_1_1), J12.1 (Pin_1_1), J13.1 (Pin_1_1), J14.1 (Pin_1_1), J15.1 (Pin_1_1), R10.1, SW1.1 (A_1), TP5.1 (1_1), U2.3 (VIN)

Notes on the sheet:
Battery Voltage Sensing
5V Buck Converter + VBUS Stuff
Test Points
Power Distrubution

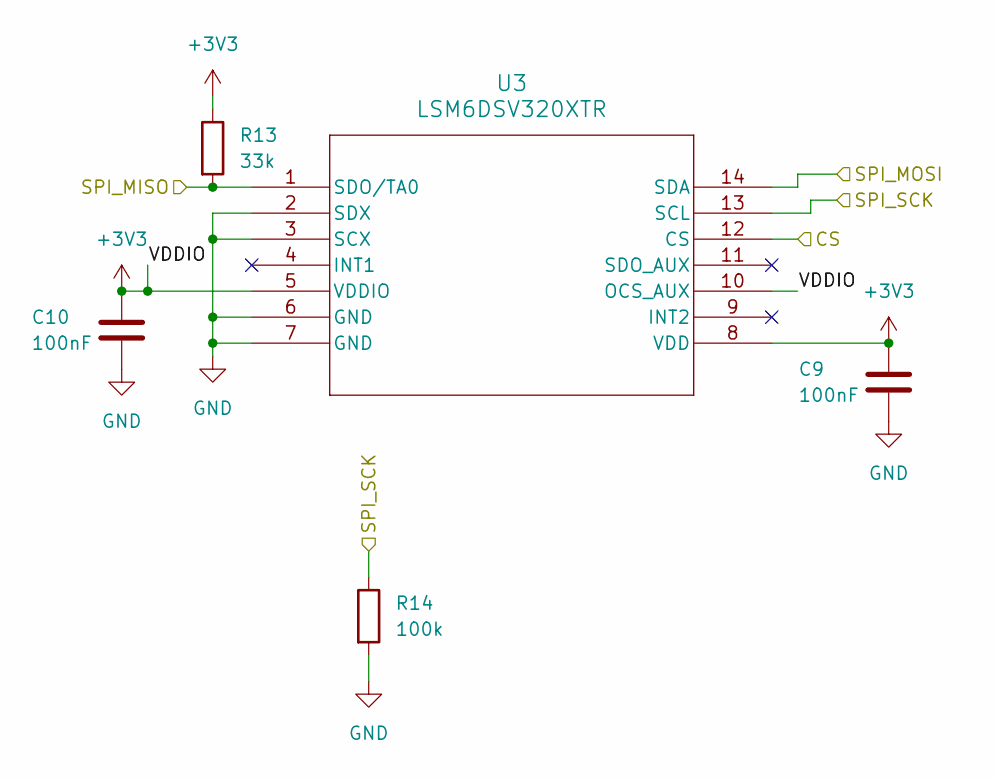
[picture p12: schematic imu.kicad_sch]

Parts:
C9, C10: 100nF; C_0805_2012Metric_Pad1.18x1.45mm_HandSolder
R13: 33k; R_0805_2012Metric_Pad1.20x1.40mm_HandSolder
R14: 100k; R_0805_2012Metric_Pad1.20x1.40mm_HandSolder
U3: LSM6DSV320XTR; LGA-14L_2p5X3X0p83_STM

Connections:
+3V3: C9.1, C10.1, R13.1, U3.5 (VDDIO), U3.8 (VDD), U3.10 (OCS_AUX); also elsewhere on the board
/SPI_CS: U3.12 (CS); also elsewhere on the board
/SPI_MISO: R13.2, U3.1 (SDO/TA0); also elsewhere on the board
/SPI_MOSI: U3.14 (SDA); also elsewhere on the board
/SPI_SCK: R14.1, U3.13 (SCL); also elsewhere on the board
GND: C9.2, C10.2, R14.2, U3.2 (SDX), U3.3 (SCX), U3.6 (GND), U3.7 (GND); also elsewhere on the board

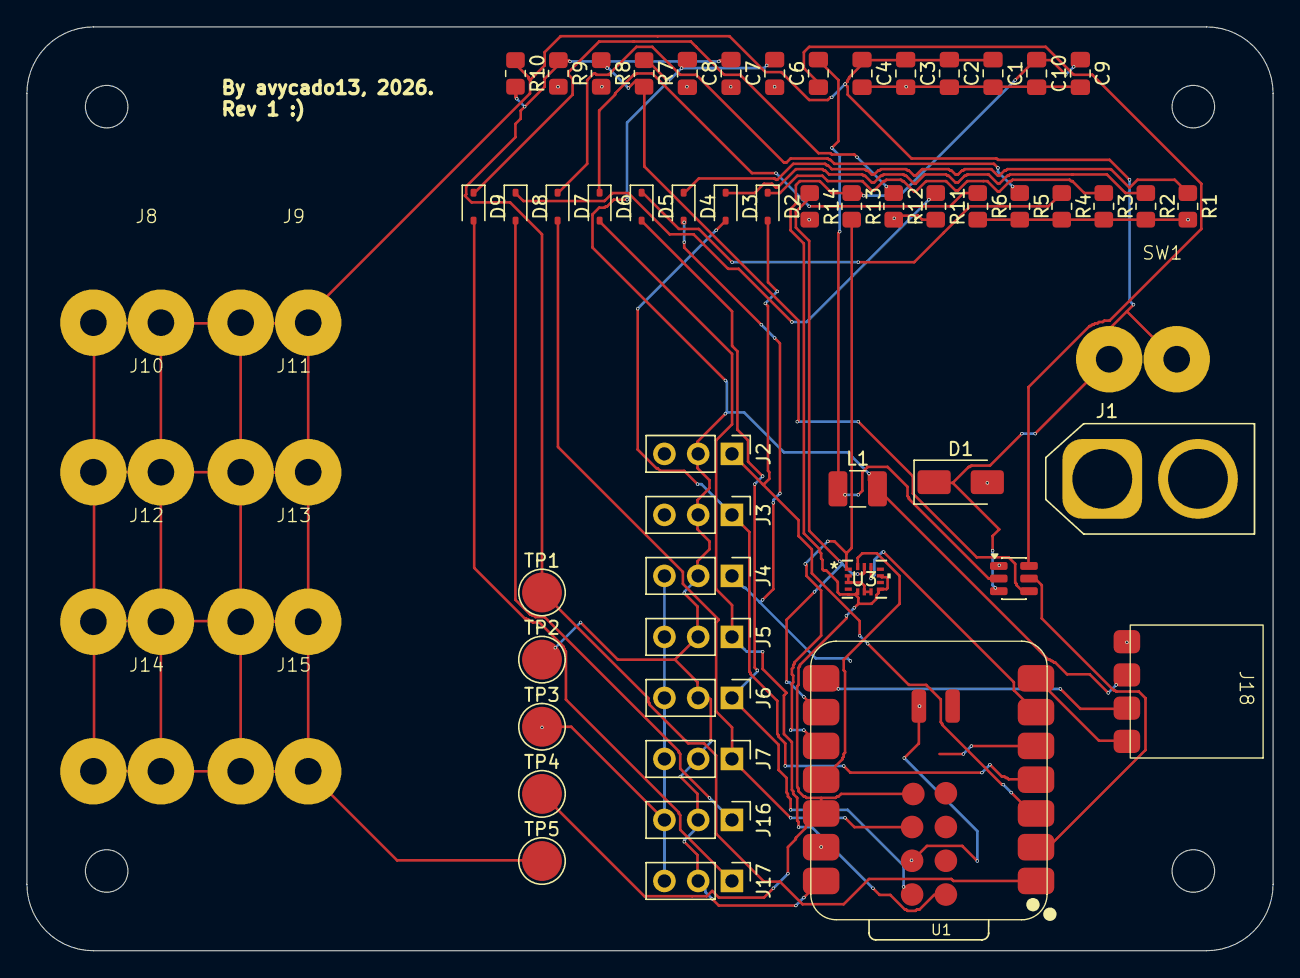
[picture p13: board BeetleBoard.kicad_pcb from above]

Board: 2 copper layers, 93.8 x 69.5 mm, 61 parts (0 on the bottom side), 31 nets.

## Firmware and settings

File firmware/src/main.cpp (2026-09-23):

/**
 * @file main.cpp
 * @brief BeetleBoard Primary Example Firmware
 * 
 * Hardware: BeetleBoard (Seeed Studio XIAO ESP32-C6)
 * Author:   avycado13
 * Features:
 *   - Battery voltage monitoring & software UVLO (TPS563200 Buck Enable control)
 *   - 6-channel ESC / Servo PWM generator (ESCs A-F)
 *   - 6-axis High-G IMU driver over SPI (LSM6DSV320XTR)
 *   - ExpressLRS (ELRS) / CRSF serial receiver decoding (UART)
 *   - Interactive Serial CLI via USB for bench testing & calibration
 *   - Multi-layer safety failsafes (UVLO shutdown, RC loss timeout, arming logic)
 */

#include <Arduino.h>
#include "beetleboard_pins.h"
#include "power_manager.h"
#include "esc_driver.h"
#include "imu_lsm6dsv.h"
#include "elrs_receiver.h"

// Subsystem instances
PowerManager powerMgr;
EscDriver    escDriver;
ImuLsm6dsv   imu;
ElrsReceiver elrs;

// Firmware operational modes
enum class TelemetryMode {
    NONE,
    IMU_STREAM,
    RC_STREAM,
    BATTERY_STREAM
};

static TelemetryMode currentTelemetry = TelemetryMode::NONE;
static uint32_t lastLedToggle = 0;
static uint32_t lastTelemetryPrint = 0;
static bool ledState = false;

// Function prototypes
void printBanner();
void printHelp();
void printStatus();
void handleSerialCommands();
void updateLedStatus();
void processRcControl();
void runMotorBenchTest(uint8_t channel);

void setup() {
    // 1. Initialize USB CDC Serial
    Serial.begin(115200);
    delay(1000); // Allow USB serial to enumerate

    // 2. Configure status LED
    pinMode(PIN_LED_BUILTIN, OUTPUT);
    digitalWrite(PIN_LED_BUILTIN, LED_INACTIVE_LEVEL);

    printBanner();

    // 3. Initialize Power Management (ADC & BUCK_EN)
    Serial.println("[INIT] Initializing Power Manager & 5V Buck Rail...");
    powerMgr.begin(true); // Enable 5V buck converter by default
    Serial.printf("       Battery: %.2fV (%dS LiPo, %.2fV/cell)\n",
                  powerMgr.getBatteryVoltage(),
                  powerMgr.getCellCount(),
                  powerMgr.getCellVoltage());

    // 4. Initialize ESC PWM Driver
    Serial.println("[INIT] Initializing 6-Channel ESC Outputs (ESCs A-F)...");
    escDriver.begin(PWM_FREQUENCY_HZ);
    escDriver.setArmed(false); // Disarmed by default for safety
    Serial.println("       ESCs initialized in DISARMED state (Safe pulse: 1000us).");

    // 5. Initialize LSM6DSV320X 6-Axis IMU over SPI
    Serial.println("[INIT] Initializing LSM6DSV320XTR 6-Axis IMU via SPI...");
    if (imu.begin()) {
        Serial.println("       IMU initialized successfully (ODR: 120Hz, ±16G / ±2000 dps).");
    } else {
        Serial.println("       [WARN] LSM6DSV320X IMU not detected! Check soldering/power.");
    }

    // 6. Initialize ExpressLRS Receiver via Serial1
    Serial.println("[INIT] Initializing ExpressLRS / CRSF Receiver Port...");
    elrs.begin(ELRS_CRSF_BAUDRATE);
    Serial.printf("       Listening on UART (RX: GPIO %d, TX: GPIO %d @ 420kBaud).\n",
                  PIN_ELRS_RX, PIN_ELRS_TX);

    Serial.println("\n[READY] BeetleBoard system ready. Type '?' or 'h' for command menu.\n");
}

void loop() {
    // 1. Update subsystem states
    powerMgr.update();
    imu.readData();
    elrs.update();

    // 2. Process RC commands or failsafes
    processRcControl();

    // 3. Handle interactive USB serial CLI
    handleSerialCommands();

    // 4. Update status LED blink pattern
    updateLedStatus();
}

/**
 * @brief Robot control loop: maps ELRS sticks to ESCs with safety interlocks.
 */
void processRcControl() {
    // If UVLO has triggered, immediately force disarm
    if (powerMgr.getBatteryState() == BatteryState::CRITICAL_UVLO) {
        if (escDriver.isArmed()) {
            escDriver.setArmed(false);
            Serial.println("[SAFETY] Critical battery undervoltage! Motors disarmed.");
        }
        return;
    }

    // Check ELRS connection
    if (elrs.isConnected()) {
        bool armSwitch = elrs.isArmSwitchActive(4); // AUX1 switch

        if (armSwitch && !escDriver.isArmed()) {
            escDriver.setArmed(true);
            Serial.println("[RC] Transmitter armed motors (AUX1 HIGH).");
        } else if (!armSwitch && escDriver.isArmed()) {
            escDriver.setArmed(false);
            Serial.println("[RC] Transmitter disarmed motors (AUX1 LOW).");
        }

        if (escDriver.isArmed()) {
            // Channel mapping:
            // Ch 0 (Roll/Steering): -1.0 to +1.0
            // Ch 1 (Pitch/Throttle): -1.0 to +1.0
            // Ch 2 (Weapon / Throttle): 0.0 to 1.0
            float steering = elrs.getChannelBidirectional(0);
            float throttle = elrs.getChannelBidirectional(1);
            float weapon   = elrs.getChannelUnidirectional(2);

            // Arcade / Differential drive mixing for ESC A (Left) & ESC B (Right)
            float leftMotor  = throttle + steering;
            float rightMotor = throttle - steering;

            // Clamp drive values
            if (leftMotor > 1.0f) leftMotor = 1.0f;
            if (leftMotor < -1.0f) leftMotor = -1.0f;
            if (rightMotor > 1.0f) rightMotor = 1.0f;
            if (rightMotor < -1.0f) rightMotor = -1.0f;

            // Drive motors on ESC A and ESC B
            escDriver.setBidirectional(static_cast<uint8_t>(EscChannel::ESC_A), leftMotor);
            escDriver.setBidirectional(static_cast<uint8_t>(EscChannel::ESC_B), rightMotor);

            // Weapon motor on ESC C (unidirectional 0.0 to 1.0)
            escDriver.setUnidirectional(static_cast<uint8_t>(EscChannel::ESC_C), weapon);

            // Auxiliary channels on ESC D, E, F
            escDriver.setPulseUs(static_cast<uint8_t>(EscChannel::ESC_D), elrs.getChannelUs(5));
            escDriver.setPulseUs(static_cast<uint8_t>(EscChannel::ESC_E), elrs.getChannelUs(6));
            escDriver.setPulseUs(static_cast<uint8_t>(EscChannel::ESC_F), elrs.getChannelUs(7));
        }
    } else {
        // Receiver disconnected or lost signal -> failsafe
        if (escDriver.isArmed()) {
            escDriver.setArmed(false);
            Serial.println("[SAFETY] ELRS RC signal lost! Failsafe triggered: Disarmed.");
        }
    }
}

/**
 * @brief Status LED blink patterns indicating health and safety status.
 */
void updateLedStatus() {
    uint32_t now = millis();
    uint32_t interval = 1000;

    if (powerMgr.getBatteryState() == BatteryState::CRITICAL_UVLO) {
        interval = 100; // Rapid emergency strobe
    } else if (powerMgr.getBatteryState() == BatteryState::LOW_WARNING) {
        interval = 250; // Fast warning blink
    } else if (escDriver.isArmed()) {
        // Solid ON when armed
        digitalWrite(PIN_LED_BUILTIN, LED_ACTIVE_LEVEL);
        return;
    } else {
        // Disarmed standby: gentle heartbeat
        interval = elrs.isConnected() ? 500 : 1000;
    }

    if (now - lastLedToggle >= interval) {
        lastLedToggle = now;
        ledState = !ledState;
        digitalWrite(PIN_LED_BUILTIN, ledState ? LED_ACTIVE_LEVEL : LED_INACTIVE_LEVEL);
    }
}

/**
 * @brief Handle user commands from the USB Serial console.
 */
void handleSerialCommands() {
    if (Serial.available()) {
        char c = Serial.read();

        // If streaming telemetry, any key stops it
        if (currentTelemetry != TelemetryMode::NONE) {
            currentTelemetry = TelemetryMode::NONE;
            Serial.println("\n[INFO] Telemetry stream stopped.");
            return;
        }

        switch (c) {
            case 'h':
            case '?':
                printHelp();
                break;

            case 's':
                printStatus();
                break;

            case 'b': {
                bool newState = !powerMgr.isBuckEnabled();
                powerMgr.setBuckEnabled(newState);
                Serial.printf("[POWER] 5V Buck Regulator manually set to: %s\n",
                              newState ? "ENABLED (HIGH)" : "DISABLED (LOW)");
                break;
            }

            case 'a': {
                bool newArmed = !escDriver.isArmed();
                escDriver.setArmed(newArmed);
                Serial.printf("[ESC] Software Arming: %s\n",
                              newArmed ? "ARMED (CAUTION: Motors Live!)" : "DISARMED (Safe)");
                break;
            }

            case 'm':
                runMotorBenchTest(0); // Test ESC A
                break;

            case 't':
                currentTelemetry = TelemetryMode::IMU_STREAM;
                Serial.println("[STREAM] Streaming IMU data (press any key to stop)...");
                Serial.println("Time(ms) | Accel_X(g) | Accel_Y(g) | Accel_Z(g) | Gyro_X(dps) | Gyro_Y(dps) | Gyro_Z(dps) | Yaw(RPM)");
                break;

            case 'r':
                currentTelemetry = TelemetryMode::RC_STREAM;
                Serial.println("[STREAM] Streaming ELRS RC Channels (press any key to stop)...");
                break;

            case 'v':
                currentTelemetry = TelemetryMode::BATTERY_STREAM;
                Serial.println("[STREAM] Streaming Battery Voltage (press any key to stop)...");
                break;

            case 'u':
                powerMgr.resetUvlo();
                Serial.println("[POWER] UVLO state cleared, 5V buck re-enabled.");
                break;

            default:
                break;
        }
    }

    // Process continuous telemetry output if active
    if (currentTelemetry != TelemetryMode::NONE && (millis() - lastTelemetryPrint >= 100)) {
        lastTelemetryPrint = millis();

        if (currentTelemetry == TelemetryMode::IMU_STREAM) {
            const auto& s = imu.getScaled();
            Serial.printf("%8lu | %+10.2f | %+10.2f | %+10.2f | %+11.1f | %+11.1f | %+11.1f | %+8.1f\n",
                          millis(), s.accelX_g, s.accelY_g, s.accelZ_g,
                          s.gyroX_dps, s.gyroY_dps, s.gyroZ_dps,
                          imu.getYawRpm());
        } else if (currentTelemetry == TelemetryMode::RC_STREAM) {
            if (elrs.isConnected()) {
                Serial.printf("Ch1:%4d Ch2:%4d Ch3:%4d Ch4:%4d AUX1:%4d | LQ:%3d%% RSSI:-%ddBm\n",
                              elrs.getChannelUs(0), elrs.getChannelUs(1),
                              elrs.getChannelUs(2), elrs.getChannelUs(3),
                              elrs.getChannelUs(4),
                              elrs.getLinkStats().uplinkLinkQuality,
                              elrs.getLinkStats().uplinkRssi1);
            } else {
                Serial.println("No ELRS signal received...");
            }
        } else if (currentTelemetry == TelemetryMode::BATTERY_STREAM) {
            Serial.printf("Vbat: %.2fV (Pin: %umV) | Cell: %.2fV (%dS) | State: %s\n",
                          powerMgr.getBatteryVoltage(),
                          powerMgr.getPinMillivolts(),
                          powerMgr.getCellVoltage(),
                          powerMgr.getCellCount(),
                          powerMgr.getBatteryState() == BatteryState::HEALTHY ? "OK" :
                          powerMgr.getBatteryState() == BatteryState::LOW_WARNING ? "LOW" :
                          powerMgr.getBatteryState() == BatteryState::CRITICAL_UVLO ? "CRITICAL" : "UNKNOWN");
        }
    }
}

/**
 * @brief Safe bench motor sweep test for testing wiring and direction.
 */
void runMotorBenchTest(uint8_t channel) {
    Serial.println("\n---------------------------------------------------------");
    Serial.printf("[TEST] Running 3-second motor bench sweep on ESC %c (GPIO %d)\n",
                  'A' + channel, escDriver.getPin(channel));
    Serial.println("       WARNING: Ensure robot is securely propped up and clear!");
    Serial.println("---------------------------------------------------------");

    escDriver.setArmed(true);

    // Ramp up from 1000us to 1250us (low safe throttle)
    for (uint16_t pulse = 1000; pulse <= 1250; pulse += 10) {
        escDriver.setPulseUs(channel, pulse);
        delay(40);
    }
    delay(500);

    // Ramp back down to 1000us
    for (uint16_t pulse = 1250; pulse >= 1000; pulse -= 10) {
        escDriver.setPulseUs(channel, pulse);
        delay(40);
    }

    escDriver.setArmed(false);
    Serial.printf("[TEST] Motor test on ESC %c complete. Disarmed.\n\n", 'A' + channel);
}

void printBanner() {
    Serial.println("\n=======================================================");
    Serial.println("        ____            __  __     ____                         __ ");
    Serial.println("       / __ )___  ___  / /_/ /__  / __ )____  ____ _________   / / ");
    Serial.println("      / __  / _ \\/ _ \\/ __/ / _ \\/ __  / __ \\/ __ `/ ___/ __  / /  ");
    Serial.println("     / /_/ /  __/  __/ /_/ /  __/ /_/ / /_/ / /_/ / /  / /_/ /_/   ");
    Serial.println("    /_____/\\___/\\___/\\__/_/\\___/_____/\\____/\\__,_/_/   \\__,_(_)    ");
    Serial.println("          Beetleweight Battlebot Firmware Example v1.0         ");
    Serial.println("=======================================================");
}

void printHelp() {
    Serial.println("\n--- BeetleBoard Interactive Console ---");
    Serial.println("  s : Print comprehensive system status");
    Serial.println("  b : Toggle 5V Buck Regulator (BUCK_EN GPIO 1)");
    Serial.println("  a : Toggle Software Arming state");
    Serial.println("  m : Run bench motor ramp test on ESC A");
    Serial.println("  t : Stream live 6-axis IMU telemetry");
    Serial.println("  r : Stream live ExpressLRS RC channels");
    Serial.println("  v : Stream live battery voltage & UVLO status");
    Serial.println("  u : Clear UVLO trip and re-enable 5V buck");
    Serial.println("  h / ? : Display this help menu");
    Serial.println("---------------------------------------\n");
}

void printStatus() {
    Serial.println("\n================ BeetleBoard System Status ================");
    
    // Power subsystem
    Serial.println("[POWER]");
    Serial.printf("  Battery Voltage:    %.2f V (Pin reading: %u mV)\n",
                  powerMgr.getBatteryVoltage(), powerMgr.getPinMillivolts());
    Serial.printf("  Detected Battery:   %dS LiPo (Average cell: %.2f V)\n",
                  powerMgr.getCellCount(), powerMgr.getCellVoltage());
    Serial.printf("  TPS563200 5V Buck:  %s\n",
                  powerMgr.isBuckEnabled() ? "ENABLED (5V rail live)" : "DISABLED (UVLO cutoff)");
    Serial.printf("  Battery Health:     %s\n",
                  powerMgr.getBatteryState() == BatteryState::HEALTHY ? "HEALTHY" :
                  powerMgr.getBatteryState() == BatteryState::LOW_WARNING ? "LOW WARNING" :
                  powerMgr.getBatteryState() == BatteryState::CRITICAL_UVLO ? "CRITICAL (UVLO TRIPPED)" : "USB POWER / UNKNOWN");

    // ESC subsystem
    Serial.println("[ESC OUTPUTS]");
    Serial.printf("  Arming Status:      %s\n", escDriver.isArmed() ? "ARMED (LIVE)" : "DISARMED (SAFE)");
    for (uint8_t i = 0; i < NUM_ESC_CHANNELS; i++) {
        Serial.printf("  ESC %c (GPIO %2d):   %4d us\n",
                      'A' + i, escDriver.getPin(i), escDriver.getPulseUs(i));
    }

    // IMU subsystem
    Serial.println("[LSM6DSV320X IMU]");
    const auto& imuData = imu.getScaled();
    Serial.printf("  Accel (g):          X:%+6.2f  Y:%+6.2f  Z:%+6.2f  (Total: %.2f g)\n",
                  imuData.accelX_g, imuData.accelY_g, imuData.accelZ_g, imu.getTotalAccelG());
    Serial.printf("  Gyro (dps):         X:%+7.1f Y:%+7.1f Z:%+7.1f (Yaw RPM: %.1f)\n",
                  imuData.gyroX_dps, imuData.gyroY_dps, imuData.gyroZ_dps, imu.getYawRpm());

    // Receiver subsystem
    Serial.println("[EXPRESSLRS / CRSF]");
    Serial.printf("  Receiver Status:    %s\n", elrs.isConnected() ? "CONNECTED" : "NO SIGNAL / DISCONNECTED");
    if (elrs.isConnected()) {
        const auto& stats = elrs.getLinkStats();
        Serial.printf("  Link Quality:       %d %%\n", stats.uplinkLinkQuality);
        Serial.printf("  Uplink RSSI:        -%d dBm\n", stats.uplinkRssi1);
        Serial.printf("  Ch1-Ch4:            %d, %d, %d, %d us\n",
                      elrs.getChannelUs(0), elrs.getChannelUs(1),
                      elrs.getChannelUs(2), elrs.getChannelUs(3));
        Serial.printf("  Arm Switch (AUX1):  %s\n", elrs.isArmSwitchActive(4) ? "HIGH (ARM)" : "LOW (DISARM)");
    }

    Serial.println("===========================================================\n");
}

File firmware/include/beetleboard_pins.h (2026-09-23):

/**
 * @file beetleboard_pins.h
 * @brief Pin definitions and board hardware configuration for BeetleBoard
 * 
 * Hardware: Seeed Studio XIAO ESP32-C6 SMD module
 * Project:  BeetleBoard (Avycado13)
 * Target:   Beetleweight Battlebot Controller
 *
 * Generated from BeetleBoard KiCad Schematics:
 * - BeetleBoard.kicad_sch
 * - power.kicad_sch
 * - imu.kicad_sch
 */

#pragma once

#include <stdint.h>

// =============================================================================
// XIAO ESP32-C6 Onboard Peripherals
// =============================================================================
// The onboard user LED is active-LOW on GPIO 15
#define PIN_LED_BUILTIN         15
#define LED_ACTIVE_LEVEL        LOW
#define LED_INACTIVE_LEVEL      HIGH

// =============================================================================
// Power & Battery Monitoring Circuitry (power.kicad_sch)
// =============================================================================
// VBAT Sensing: Voltage divider with R10 (120kΩ) and R9 (33.2kΩ), C7 (100nF) filter
// Connected to XIAO Pin D0 (ESP32-C6 GPIO 0 / ADC1_CH0)
#define PIN_VBAT_SNS            0

// Buck Converter Enable: Controls EN pin of TPS563200 3A 5V Buck Regulator (U2)
// Connected to XIAO Pin D1 (ESP32-C6 GPIO 1)
// Active-HIGH: Set HIGH to enable 5V rail; set LOW for software UVLO shutdown
#define PIN_BUCK_EN             1

// Resistor divider values for VBAT calculation:
// V_sns = V_bat * (R_BOTTOM / (R_TOP + R_BOTTOM))
// V_bat = V_sns * ((R_TOP + R_BOTTOM) / R_BOTTOM)
#define VBAT_DIVIDER_R_TOP      120000.0f   // 120 kΩ (R10)
#define VBAT_DIVIDER_R_BOTTOM   33200.0f    // 33.2 kΩ (R9)
#define VBAT_DIVIDER_RATIO      (VBAT_DIVIDER_R_BOTTOM / (VBAT_DIVIDER_R_TOP + VBAT_DIVIDER_R_BOTTOM)) // ~0.21671
#define VBAT_SCALE_FACTOR       ((VBAT_DIVIDER_R_TOP + VBAT_DIVIDER_R_BOTTOM) / VBAT_DIVIDER_R_BOTTOM) // ~4.61446

// =============================================================================
// ESC / Motor Signal Ports (BeetleBoard.kicad_sch)
// =============================================================================
// 6 ESC ports connected directly to ESP32-C6 GPIOs with ESD protection (D2-D7)
// and 33k pull-downs (R1-R6). Connectors are standard 3-pin 0.1" (Signal, 5V, GND).
#define NUM_ESC_CHANNELS        6

#define PIN_ESC_A               2    // J2: XIAO D2 (GPIO 2)
#define PIN_ESC_B               21   // J3: XIAO D3 (GPIO 21)
#define PIN_ESC_C               22   // J4: XIAO D4 (GPIO 22)
#define PIN_ESC_D               5    // J5: XIAO MTDI (GPIO 5)
#define PIN_ESC_E               7    // J6: XIAO MTDO (GPIO 7)
#define PIN_ESC_F               6    // J7: XIAO MTCK (GPIO 6)

// Note: Ports ESC_G (J16) and ESC_H (J17) exist on the PCB with ESD protection
// and pull-downs, but their signal pins are unrouted to the MCU on this revision.
#define PIN_ESC_G_CONNECTED     0
#define PIN_ESC_H_CONNECTED     0

// Array of active ESC pins for easy iteration
static const uint8_t ESC_PINS[NUM_ESC_CHANNELS] = {
    PIN_ESC_A,  // Channel 0 (ESC A)
    PIN_ESC_B,  // Channel 1 (ESC B)
    PIN_ESC_C,  // Channel 2 (ESC C)
    PIN_ESC_D,  // Channel 3 (ESC D)
    PIN_ESC_E,  // Channel 4 (ESC E)
    PIN_ESC_F   // Channel 5 (ESC F)
};

// =============================================================================
// 6-Axis High-G IMU: LSM6DSV320XTR (imu.kicad_sch)
// =============================================================================
// Communicates over dedicated 4-wire SPI bus (3.3V logic)
#define PIN_IMU_CS              23   // U3 Pin 12: XIAO D5 (GPIO 23)
#define PIN_IMU_SCK             19   // U3 Pin 13: XIAO D8 (GPIO 19, R14 100k pulldown)
#define PIN_IMU_MISO            20   // U3 Pin 1:  XIAO D9 (GPIO 20, R13 33k pullup)
#define PIN_IMU_MOSI            18   // U3 Pin 14: XIAO D10 (GPIO 18)

// LSM6DSV320X Device ID & SPI Speeds
#define LSM6DSV320X_WHO_AM_I_VAL 0x73
#define IMU_SPI_CLOCK_HZ        4000000 // 4 MHz SPI clock

// =============================================================================
// ExpressLRS (ELRS) / CRSF Receiver Port (BeetleBoard.kicad_sch)
// =============================================================================
// J18: 4-pin header for BetaFPV Lite / ExpressLRS receivers (TX, RX, 5V, GND)
#define PIN_ELRS_TX             16   // J18 Pin 1: XIAO D6 (GPIO 16) -> Receiver RX
#define PIN_ELRS_RX             17   // J18 Pin 2: XIAO D7 (GPIO 17) <- Receiver TX
#define ELRS_CRSF_BAUDRATE      420000  // Standard CRSF baud rate
#define ELRS_SERIAL_PORT        Serial1
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

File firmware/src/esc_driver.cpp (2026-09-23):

/**
 * @file esc_driver.cpp
 * @brief Implementation of ESC PWM generation for BeetleBoard
 */

#include "esc_driver.h"
#include <esp_arduino_version.h>

EscDriver::EscDriver() {}

void EscDriver::begin(uint32_t frequencyHz) {
    _frequencyHz = frequencyHz;
    _periodUs = 1000000UL / _frequencyHz;
    _resolutionBits = 14; // 14-bit resolution at 50Hz gives ~1.22us per tick
    _maxDuty = (1UL << _resolutionBits) - 1;

    for (uint8_t i = 0; i < NUM_ESC_CHANNELS; i++) {
        uint8_t pin = ESC_PINS[i];
#if defined(ESP_ARDUINO_VERSION_MAJOR) && (ESP_ARDUINO_VERSION_MAJOR >= 3)
        // Modern ESP32 Core 3.x LEDC API
        ledcAttach(pin, _frequencyHz, _resolutionBits);
        ledcWrite(pin, usToDuty(PWM_DISARM_US));
#else
        // Legacy ESP32 Core 2.x LEDC API
        ledcSetup(i, _frequencyHz, _resolutionBits);
        ledcAttachPin(pin, i);
        ledcWrite(i, usToDuty(PWM_DISARM_US));
#endif
        _channelPulses[i] = PWM_DISARM_US;
    }
}

uint32_t EscDriver::usToDuty(uint16_t pulseUs) const {
    if (pulseUs > _periodUs) pulseUs = _periodUs;
    return ((uint64_t)pulseUs * _maxDuty) / _periodUs;
}

void EscDriver::setArmed(bool armed) {
    _armed = armed;
    if (!_armed) {
        emergencyStop();
    }
}

void EscDriver::emergencyStop() {
    for (uint8_t i = 0; i < NUM_ESC_CHANNELS; i++) {
        setPulseUs(i, PWM_DISARM_US);
    }
}

void EscDriver::setPulseUs(uint8_t channel, uint16_t pulseUs) {
    if (channel >= NUM_ESC_CHANNELS) return;

    // Safety clamp
    if (pulseUs < PWM_PULSE_MIN_US) pulseUs = PWM_PULSE_MIN_US;
    if (pulseUs > PWM_PULSE_MAX_US) pulseUs = PWM_PULSE_MAX_US;

    // If disarmed, force stop pulse
    if (!_armed) {
        pulseUs = PWM_DISARM_US;
    }

    _channelPulses[channel] = pulseUs;
    uint32_t duty = usToDuty(pulseUs);
    uint8_t pin = ESC_PINS[channel];

#if defined(ESP_ARDUINO_VERSION_MAJOR) && (ESP_ARDUINO_VERSION_MAJOR >= 3)
    ledcWrite(pin, duty);
#else
    ledcWrite(channel, duty);
#endif
}

void EscDriver::setUnidirectional(uint8_t channel, float throttle) {
    if (throttle < 0.0f) throttle = 0.0f;
    if (throttle > 1.0f) throttle = 1.0f;

    uint16_t pulse = (uint16_t)(PWM_PULSE_MIN_US + throttle * (PWM_PULSE_MAX_US - PWM_PULSE_MIN_US));
    setPulseUs(channel, pulse);
}

void EscDriver::setBidirectional(uint8_t channel, float throttle) {
    if (throttle < -1.0f) throttle = -1.0f;
    if (throttle > 1.0f) throttle = 1.0f;

    uint16_t pulse;
    if (throttle >= 0.0f) {
        pulse = (uint16_t)(PWM_PULSE_NEUTRAL_US + throttle * (PWM_PULSE_MAX_US - PWM_PULSE_NEUTRAL_US));
    } else {
        pulse = (uint16_t)(PWM_PULSE_NEUTRAL_US + throttle * (PWM_PULSE_NEUTRAL_US - PWM_PULSE_MIN_US));
    }
    setPulseUs(channel, pulse);
}

uint16_t EscDriver::getPulseUs(uint8_t channel) const {
    if (channel >= NUM_ESC_CHANNELS) return 0;
    return _channelPulses[channel];
}

uint8_t EscDriver::getPin(uint8_t channel) const {
    if (channel >= NUM_ESC_CHANNELS) return 255;
    return ESC_PINS[channel];
}

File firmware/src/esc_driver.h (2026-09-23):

/**
 * @file esc_driver.h
 * @brief Multi-channel ESC and Servo PWM driver for BeetleBoard (ESCs A-F)
 */

#pragma once

#include <Arduino.h>
#include "beetleboard_pins.h"

enum class EscChannel : uint8_t {
    ESC_A = 0,
    ESC_B = 1,
    ESC_C = 2,
    ESC_D = 3,
    ESC_E = 4,
    ESC_F = 5
};

class EscDriver {
public:
    EscDriver();

    /**
     * @brief Initialize LEDC PWM timers and attach pins for all 6 ESC channels.
     * @param frequencyHz PWM frequency (typically 50Hz for standard RC / servos, up to 400Hz).
     */
    void begin(uint32_t frequencyHz = PWM_FREQUENCY_HZ);

    /**
     * @brief Arm or disarm ESCs. When disarmed, pulses are set to safe stop.
     */
    void setArmed(bool armed);

    /**
     * @brief Check whether outputs are currently armed.
     */
    bool isArmed() const { return _armed; }

    /**
     * @brief Immediately cut all motor outputs to stop pulse width.
     */
    void emergencyStop();

    /**
     * @brief Set pulse width directly in microseconds (1000 - 2000 us).
     * @param channel Index 0 to 5 (or EscChannel enum).
     * @param pulseUs Pulse duration in microseconds.
     */
    void setPulseUs(uint8_t channel, uint16_t pulseUs);
    void setPulseUs(EscChannel channel, uint16_t pulseUs) {
        setPulseUs(static_cast<uint8_t>(channel), pulseUs);
    }

    /**
     * @brief Set throttle normalized from 0.0 (stop) to 1.0 (full speed).
     */
    void setUnidirectional(uint8_t channel, float throttle);

    /**
     * @brief Set bidirectional throttle from -1.0 (reverse) to 0.0 (stop) to +1.0 (forward).
     */
    void setBidirectional(uint8_t channel, float throttle);

    /**
     * @brief Read back current commanded pulse width in microseconds.
     */
    uint16_t getPulseUs(uint8_t channel) const;

    /**
     * @brief Return the GPIO pin number for a given ESC channel.
     */
    uint8_t getPin(uint8_t channel) const;

private:
    uint32_t usToDuty(uint16_t pulseUs) const;

    bool _armed = false;
    uint32_t _frequencyHz = 50;
    uint8_t _resolutionBits = 14;
    uint32_t _periodUs = 20000;
    uint32_t _maxDuty = 16383;

    uint16_t _channelPulses[NUM_ESC_CHANNELS] = {
        PWM_PULSE_MIN_US, PWM_PULSE_MIN_US, PWM_PULSE_MIN_US,
        PWM_PULSE_MIN_US, PWM_PULSE_MIN_US, PWM_PULSE_MIN_US
    };
};

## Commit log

2026-09-10 fix power schematic and decide to just do undervolt protection in software
    [power.kicad_sch]
2026-09-10 add ESC Ports
    [BeetleBoard.kicad_sch, power.kicad_sch]
2026-09-10 add IMU
    [BeetleBoard.kicad_sch, power.kicad_sch]
2026-09-11 fix power distrubution
    [BeetleBoard.kicad_sch, power.kicad_sch]
2026-09-11 add revised IMU
    [BeetleBoard.kicad_sch, imu.kicad_sch, power.kicad_sch]
2026-09-12 add ELRS Reciever and clean up some stuff
    [BeetleBoard.kicad_sch, imu.kicad_sch, power.kicad_sch]
2026-09-14 clean up schematics and start pcb
    [BeetleBoard.kicad_pcb, BeetleBoard.kicad_sch, imu.kicad_sch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]
2026-09-14 redo layout and wire it up
    [BeetleBoard.kicad_pcb]
2026-09-14 fix up for shipping
    [BeetleBoard.kicad_pcb]
2026-09-20 Fix README.md and add BOM
2026-09-20 add boms with part numbers and prices from octopart
    [BOM.csv, LCSC.csv, mouser.csv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]
2026-09-21 journal bom time and update time spent for readme
2026-09-22 Reorganise PCB and make it neat
    [BeetleBoard.kicad_pcb, power.kicad_sch]
2026-09-23 make pcb nicer and add firmware written by ai
    [BeetleBoard.kicad_pcb, bom.csv, designators.csv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]
2026-10-03 Thicken power traces and some cleanup
